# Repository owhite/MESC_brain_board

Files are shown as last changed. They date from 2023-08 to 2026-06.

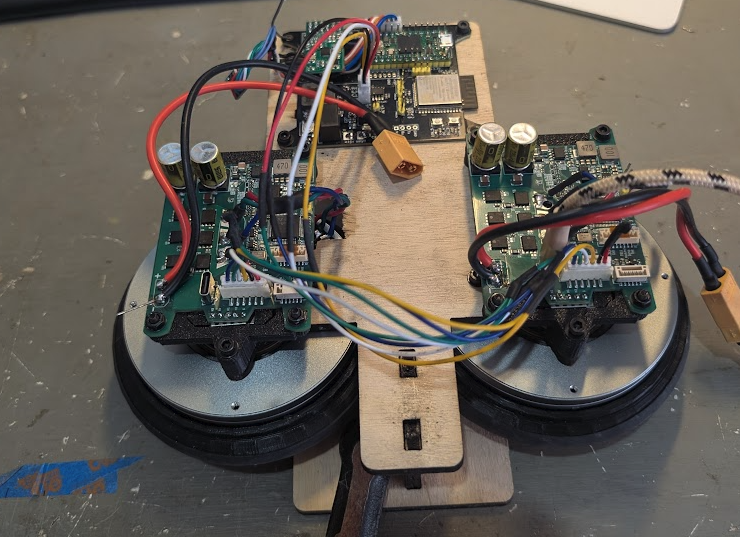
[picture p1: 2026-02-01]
DOCS/IMAGES/ROBOT_CARCASS1.png

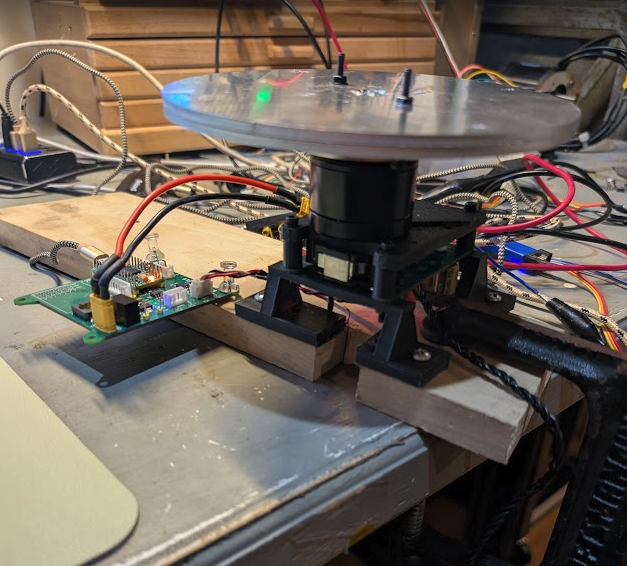
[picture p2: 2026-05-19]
modeling/PICS/rig2.png

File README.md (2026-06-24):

# Balancing Robot Design and Implementation

This repository is a structured set of lab notes and implementation records for developing a two-wheeled self-balancing robot. It documents the workflows from physical modeling and parameter measurement through firmware design, control implementation, and experimental validation.

The focus is on reproducibility and engineering rigor: measured motor parameters, deterministic control-loop behavior, system identification, control design tradeoffs, and verification testing are all captured alongside working code and experiments.

Topics covered include:
- Control design and validation workflows for balancing robots
- Motor parameter measurement (phase resistance, d/q inductance, damping)
- Deterministic embedded firmware structure for real-time control
- Encoder integration and signal integrity checks
- CAN communication and timing behavior
- Failure modes and debugging notes
- Practical test methods and instrumentation results

These notes are intended to make the development and validation process transparent and repeatable, not just to present final code.

## My balancing robot journey, specs and testing

* A subset of steps required to get a robot to stand [[LINK](DOCS/balancing_checklist.md)]
* Common issues that can break balancing in the brain board project [[LINK](DOCS/balancing_failures.md)]
* Firmware design choices that keep the balancing control loop deterministic [[LINK](DOCS/determinism_design.md)]
* Measuring phase resistance, d-axis, and q-axis inductance of a BLDC Motor [[LINK](DOCS/BLDC_inductance_measurement.md)]
* Dial in ChatGPT to be skeptical lab partner: [[LINK](DOCS/chatGPT_tips.md)]
* Development of the robot control board [[LINK](brainboardV1.2/README.md)]
* OTA programming [[LINK](RPI_OTA_BRIDGE/README.md)]
* Finalizing the modeling workflow [[LINK](modeling/README.md)]

## Not totally coherent discussions:
* [LQR](DOCS/learn_LQR.md). 
* Using the MT6701 [[LINK](DOCS/MT6701.md)] → works great but required some minor modifications to MESC position and [velocity measurement](DOCS/pos_vel_CAN.md)
* Measuring jitter on the MESC [[LINK](DOCS/jitter_testing.md)] → none found at current operating speeds
* Implementing CAN [[LINK](DOCS/CAN.md)]
* Notes about MESC [[LINK](DOCS/MESC_control_variables.md)]
* The inadequacies of PID [[LINK](DOCS/PID_position.md)]. 
* General description of firmware: [LINK](DOCS/teensy_firmware_walkthrough.md). 
* Brain board firmware [[LINK](DOCS/software_specs.md)]

## Laboratory notes, 2025

* [Position hold](DOCS/sept12_position_hold.md)
* [Controller issues](DOCS/sept18_controller_issues.md)
* [Torque nonlinearity](DOCS/sept19_torque_nonlinearity.md)
* [PID notes](DOCS/sept23_PID_notes.md)
* [Least squares](DOCS/sept30_least_squares.md)
* [Torque response](DOCS/oct03_torque_response.md)
* [LQR modeling](DOCS/oct11_LQR_modeling.md)
* [LQR height](DOCS/oct12_LQR_height.md)
* [IMU testing](DOCS/nov16_IMU.md)

## Let's be real

**You probably will not want to hear this.** If you came here for the code to make a balancing robot, it is here, but it probably wont help. 

You might assume building a balancing robot is mostly a matter of assembling parts and flashing someone else’s code onto it. I used to think that too — until I finally worked out how to create on one. Balancing robots are not just bolted together -- they are tuned and integrated. Everything about them depends on tight interactions between hardware, sensors, motors, and feedback loops, and those interactions are different for every single robot.

A balancing robot is a dynamic control system, not a static device. It’s constantly trying to predict its own motion, measure its own tilt, compensate for delays, cancel vibration, and stabilize itself against gravity — hundreds of times per second. That means even small differences in hardware completely change the way the controller behaves. For example:

- Motors & ESCs: Different torque curves, different dead zones, different current limits, different FOC tuning.
- Wheels & tires: Diameter, traction, inertia, compliance — all change how the robot responds to torque.
- IMU: Sensitivity, noise, mounting vibration, sample timing, bias drift — all affect measured tilt.
- Microcontroller timing: Loop rate, jitter, scheduling delays, filter performance — all shift the controller behavior.
- Physical build: Height of the center of mass, frame stiffness, mass distribution — all change the robot’s dynamics.

If you change any of these, even slightly, the controller behaves differently. That’s why tuning is so time-consuming: you’re adjusting a control law to match the physics and imperfections of your specific robot.

_You are welcome to take my code and run it on your bot._ But unfortunately just like musical instruments or high-performance cars, balancing robots need to be customized, adjusted, and dialed in until the system “feels right.” The code is just the beginning; the tuning is the craft.

Why? Well:
- Your robot will not balance without a lot of tuning.
- What's most important to use this project as a prompt for making your own system
- Tuning is the real work — not a flaw, but part of the fun
- What really makes a robot stand is eliminating all the problems like jitter, timing issues, CAN communications, and modeling

**Finally, dearest reader**... I care about you, youre adorable, but quite unfortunately one the PCB for one of the ESCs that I use is closed source. Nothing would delight me more to make it open and I will try. For a while, I was using the Flipsky Mini FSESC6.7 pro 70A but I got tired of blowing them up because of cheap parts. Some day I will make a balancing bot that runs on [moteus](https://mjbots.com/products/moteus-r4-11) or [odrive](https://odriverobotics.com) but right now that is not a priority. 

For these reasons and others you cant expect to use this repo to build a balancing robot like some sort of kit.

## The really great news is there is a new source of help. 

I want to be transparent about this: building a robot is not about writing code. I've written code for 20 plus years, in my case I worked through the entire project with ChatGPT as a kind of engineering partner. ChatG helps with asking questions, testing ideas, refining approaches, debugging weird behavior, and iterating the design over and over.

A balancing robot is a complex closed-loop control problem. As far as I know I never would have been able to use Google to address how robots behaves. ChatGPT creates the ability to explore those problems conversationally:

- When I wasn’t sure whether the IMU filtering was right, I asked it to analyze my data.
- It is incredible at helping with plotting results
- When I had motor vibration I couldn’t explain, I used chat to brainstorm possible causes and experiments.
- It taught me everything about LQR, interpretted equations, supplied python code to perform most of the calculations. It involved a lot of debugging -- when the LQR gains seemed wrong, I walked through the math with it.
- When the ESC behavior looked inconsistent, we debugged line by line until we understood it.
- When I needed to test an assumption, it helped me design the test.
- When something behaved strangely, I could describe it and get three possible hypotheses to try.
- ChatG is uncanny at image analysis. It reads part numbers off of chips and will take you to the spec sheet. Take a picture of a square wave of your scope - - the damn thing will tell you the frequency, amplitude of the wave. It also taught me how to set up [one-shot measurements](DOCS/BLDC_inductance_measurement.md). 

The project was far less like copying code from the internet and more like having a very patient senior engineer building one-off code bundles to eventually get this thing to stand. 

**We live in a world of prompt-driven engineering:** I shaped my thinking through prompts, refined those prompts based on the robot’s behavior, and used those conversations to build understanding that would have taken months on my own. ChatGPT didn’t “solve the problem” — it helped me reason through it, step by step.

So if you see this robot standing and balancing in a video, know that behind the scenes was not just hardware and code — it was hundreds of micro-conversations, experiments, adjustments, and iterations. ChatGPT was the scaffolding that helped me structure that process.

## ACKNOWLEDGEMENTS
This project would be completely impossible without the help, support and guidance of David Molony, developer of [MESC firmware](https://github.com/davidmolony/MESC_Firmware.git). Use of the MESC firmware is described throughout this repo.

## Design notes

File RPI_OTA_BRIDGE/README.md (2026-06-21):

# Headless Teensy OTA Bridge (Pi Zero 2 W)

Reference commit: `89e9f187`
Date: 2026-05-05
This codebase was created from the prompt in [PROMPT.md](PROMPT.md).

## To invoke upload

Documentation update reference commit: `c7eb63e1`

Working method (validated): run from your PlatformIO project that contains `bridge_upload.py` and its `platformio.ini` wiring (example project: `teensy40/blink`).

```bash
cd /path/to/teensy40/blink
pio run -t bridge_send
```

The same command with explicit overrides:

```bash
TEENSY_BRIDGE_HOST=teensybridge.local TEENSY_BRIDGE_USER=owhite TEENSY_BRIDGE_DROP_DIR=/home/owhite/teensy_drops pio run -t bridge_send
```

Help command for this integration:

```bash
pio run -t bridge_help
```

Optional wrapper commands (if `pio_bridge.sh` is present in that PlatformIO project root):

```bash
./pio_bridge.sh --bridge_help
./pio_bridge.sh --bridge_send
```

What does not work from this repository root (`RPI_OTA_BRIDGE`) unless you add those custom targets to that project:

```bash
pio run -t bridge_send
pio run -t bridge_help
```

**NOTE:** some times you have to press the button on the teensy, but usually just for the first upload of the session. 

## Upload/Download Expansion Plan

For the new Teensy -> Pi -> Desktop run-log return pipeline, use:

- [RPI_UPLOAD_DOWNLOAD_CHECKLIST.md](RPI_UPLOAD_DOWNLOAD_CHECKLIST.md)

Phase 1 implementation reference commit: `c7eb63e1`

## Construction notes

This workspace implements your spec for a headless Raspberry Pi OTA bridge:

- Desktop -> Pi transport via `scp`
- Pi-side file completion trigger via Linux inotify (Python Watchdog `on_closed`)
- Flash target via `teensy_loader_cli --mcu=TEENSY40 -w -s -v`
- Upload status persisted to `/home/<your_pi_username>/teensy_drops/last_upload_status.log`
- Processed artifacts (`.hex`) moved to `/home/<your_pi_username>/teensy_drops/processed`

## Project Layout

- `pi/udev/49-teensy.rules`: non-root Teensy bootloader access
- `pi/scripts/install_teensy_loader_cli.sh`: build/install PJRC loader on ARM
- `pi/scripts/install_udev_rules.sh`: deploy udev rule to `/etc/udev/rules.d/`
- `pi/bridge/bridge.py`: watchdog service implementation
- `pi/bridge/requirements.txt`: optional Python dependency list (`watchdog`)
- `pi/systemd/teensy-bridge.service`: persistent service unit
- `pi/scripts/install_bridge_service.sh`: install Python dependency and systemd service
- `pi/listener/serial_listener.py`: Pi-side Teensy USB serial capture worker
- `pi/systemd/teensy-listener.service`: persistent Teensy serial listener unit
- `pi/scripts/install_listener_service.sh`: install serial listener dependency and service
- `desktop/upload_to_pi.py`: PlatformIO post-upload script (SCP + SSH log follow)
- `desktop/platformio.ini.snippet`: required PlatformIO config snippet

## mounted Pi: 
pi mount

## Pi Provisioning Baseline

Raspberry Pi OS Lite (64-bit), hostname `teensybridge`, SSH enabled, Wi-Fi configured.

Note: Connect using mDNS name `teensybridge.local` from your desktop.

Required packages from spec are covered by scripts:

- `build-essential`
- `libusb-dev`
- `python3-watchdog`
- `git`

Note: On Raspberry Pi OS trixie (PEP 668), the bridge installer uses `python3-watchdog` from apt instead of pip.

## Pi Installation Steps

Run these on the Pi from this repository root:

```bash
chmod +x pi/scripts/*.sh
./pi/scripts/install_teensy_loader_cli.sh
./pi/scripts/install_udev_rules.sh
./pi/scripts/install_bridge_service.sh
./pi/scripts/install_listener_service.sh
```

If your Pi login user is not `pi`, set `BRIDGE_USER` before the bridge install step:

```bash
export BRIDGE_USER=<your_pi_username>
./pi/scripts/install_bridge_service.sh
./pi/scripts/install_listener_service.sh
```

The installer renders the systemd unit with your user home and sets `TEENSY_DROP_DIR` automatically.

Then verify:

```bash
systemctl status teensy-bridge.service --no-pager
systemctl status teensy-listener.service --no-pager
journalctl -u teensy-bridge.service -n 50 --no-pager
journalctl -u teensy-listener.service -n 50 --no-pager
```

Quick listener smoke test (on Pi):

```bash
RUN_ID=$(date +%Y%m%d_%H%M%S)_smoke
echo "$RUN_ID" > /home/$USER/teensy_runs/current_run_id
sleep 2
cat /home/$USER/teensy_runs/$RUN_ID/status.json
```

Completion marker note:

- The listener marks a run `completed` on either:
	- JSON line with `"msg":"RUN_DONE"` (optional matching `run_id`), or
	- plain-text line containing `RUN_DONE` (optionally `RUN_ID=<run_id>`).

Listener growth safety defaults:

- Per-run timeout: `RUN_TIMEOUT_SEC=120`
- Per-run byte cap: `MAX_RUN_BYTES=20971520` (20 MiB)
- Per-run record cap: `MAX_RUN_RECORDS=200000`
- Old run retention cap: `KEEP_RUN_DIRS=200` (oldest run directories are pruned)

Additional safety behavior:

- Run logs are overwritten per run ID (not appended) to prevent restart replay growth.
- Completed/timed-out/error runs are not replayed on service restart.

## Desktop PlatformIO Integration

Validated current workflow (recommended):

1. Use your PlatformIO project with bridge targets already wired (example: `teensy40/blink`).
2. From that project directory run:

```bash
pio run -t bridge_send
```

3. Optional environment overrides:

```bash
export TEENSY_BRIDGE_HOST=teensybridge.local
export TEENSY_BRIDGE_USER=<your_pi_username>
export TEENSY_BRIDGE_DROP_DIR=/home/<your_pi_username>/teensy_drops
```

If your Pi hostname differs, set `TEENSY_BRIDGE_HOST` accordingly.

Alternative workflow (this repo's generic hook):

1. Copy `desktop/upload_to_pi.py` into your PlatformIO project root.
2. Add contents of `desktop/platformio.ini.snippet` to your `platformio.ini`.
3. Run `pio run -t upload` from that PlatformIO project.

## One-Command Run Cycle (Desktop)

Desktop orchestration reference commit: `c7eb63e1`

Use this script to run one full cycle:

1. write a new `run_id` on Pi (`current_run_id`)
2. build + upload firmware (`pio run -t bridge_send`)
3. wait for Pi listener terminal status (`completed`, `timed_out`, `error`, `size_limit`)
4. fetch `/home/<pi_user>/teensy_runs/<run_id>/` artifacts to local logs

From this repository root:

```bash
./desktop/run_cycle.py --firmware-dir /path/to/teensy40/blink --user owhite --host teensybridge.local
```

Optional arguments:

```bash
./desktop/run_cycle.py \
	--firmware-dir /path/to/teensy40/blink \
	--logs-dir ./logs \
	--wait-timeout 240 \
	--keep-local-runs 100 \
	--user owhite \
	--host teensybridge.local
```

Local retention behavior:

- `--keep-local-runs` (default `100`) prunes oldest local run directories in `--logs-dir` after each run.

Exit behavior:

- `0`: run completed and artifacts fetched
- `124`: listener timed out or wait timeout exceeded
- nonzero: build/upload/fetch/listener error

## Full End-to-End Cycle (Runbook)

Documentation cycle reference commit: `c7eb63e1`

Use this sequence for the complete workflow:

1. Confirm Pi services are active:

```bash
ssh owhite@teensybridge.local "systemctl is-active teensy-bridge.service teensy-listener.service"
```

2. Run one full desktop cycle (build -> flash -> wait -> fetch):

```bash
cd /Users/owhite/balancing-robot-notes/RPI_OTA_BRIDGE
./desktop/run_cycle.py --firmware-dir /Users/owhite/balancing-robot-notes/teensy40/RPI_upload_download --user owhite --host teensybridge.local
```

3. Find the newest fetched run directory:

```bash
LATEST_RUN="$(ls -1t logs | head -n 1)"
echo "$LATEST_RUN"
ls -la "logs/$LATEST_RUN"
```

4. Verify outcome and key metrics:

```bash
cat "logs/$LATEST_RUN/status.json"
```

Expected success shape:

- `state` is `completed`
- `error` is empty
- `records` and `bytes` are nonzero

5. Inspect captured logs:

```bash
head -n 20 "logs/$LATEST_RUN/serial_raw.log"
head -n 20 "logs/$LATEST_RUN/serial_parsed.jsonl"
```

Expected log semantics:

- first meaningful marker is `RUN_START`
- periodic data lines follow
- completion marker `RUN_DONE` is present

If run ends as `timed_out` but artifacts exist, transport/capture worked and completion marker was not observed before timeout.

## Runtime Behavior

On upload:

1. Desktop script clears the remote status log and ensures drop directories exist.
2. Desktop script copies firmware (`.hex`) via `scp`.
3. Pi watchdog sees a file close event (`on_closed`) for `.hex` and runs teensy loader.
4. Desktop script streams `tail -f /home/<your_pi_username>/teensy_drops/last_upload_status.log`.
5. Desktop script exits success only when `EXIT_CODE=0`; otherwise exits with error.

## Notes

- The bridge is intentionally headless and unattended.
- Processed firmware is renamed with timestamp and result suffix (`.ok.hex` or `.fail.hex`).
- Soft reboot mode (`-s`) avoids button presses when the running firmware exposes a USB path that supports reboot requests.
- If firmware is crashed or USB is unavailable, manual button press may still be required.
- Trigger semantics: upload starts on inotify `on_closed` for new `.hex` writes in the drop folder.

## Known Failure Modes

1. **No USB events on Pi (`dmesg -w` stays silent)**
	- Symptom: plugging/unplugging Teensy shows nothing in `sudo dmesg -w`.
	- Cause: wrong Pi Zero 2 W port (`PWR IN` instead of `USB` data), bad OTG adapter, or charge-only cable.
	- Fix: use the `USB` data port with a known data cable/OTG adapter; verify events appear in `dmesg -w`.

2. **SSH key login fails (`Permission denied (publickey)`)**
	- Symptom: `ssh <user>@teensybridge.local` reaches host, then auth fails.
	- Cause: wrong SSH username or mismatched key in Imager/authorized_keys.
	- Fix: connect with the correct username; verify matching key pair; use password auth for first boot if needed.

3. **`externally-managed-environment` during install**
	- Symptom: pip install fails on Raspberry Pi OS trixie.
	- Cause: PEP 668 system Python protections.
	- Fix: installer uses apt package `python3-watchdog`; avoid system pip installs for bridge dependency.

4. **Loader waits forever (`Waiting for Teensy device...`)**
	- Symptom: `teensy_loader_cli` parses firmware then waits for device.
	- Cause: Teensy bootloader not entered yet, USB path unavailable, or firmware cannot soft-reboot.
	- Fix: try `-s` soft reboot path first; if still waiting, press Teensy button; confirm USB visibility with `lsusb`/`dmesg`.

5. **HEX/BIN mismatch parse errors**
	- Symptom: errors like `error reading intel hex file ...firmware.bin`.
	- Cause: dropping `.bin` while loader expects Intel HEX.
	- Fix: bridge is `.hex`-only; ensure desktop uploader transfers `.hex` artifacts.

6. **Upload not triggered even with file in drop folder**
	- Symptom: old file present but no flash attempt.
	- Cause: trigger is event-based (`on_closed`), not presence-based.
	- Fix: copy/write a new `.hex` file into the drop directory; stale files do not retrigger.

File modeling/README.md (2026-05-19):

# Pendulum State-space Model Generation and Validation

## GOAL: Develop a final workflow for determining the gains to run a two wheel robot (TWR)

The intention here is to create a reproducible workflow for generating and validating the balancing robot model and LQR controller gains. Physical parameters are derived from CAD STL geometry and measured part masses, then automatically converted to SI units and used to compute CoM, inertia, and the linearized state-space model.

Model correctness is verified through automated checks including controllability/observability rank, continuous and discrete closed-loop pole analysis, time-constant estimation, and time-domain closed-loop simulation with actuator effort plots. This validation pipeline ensures the controller gains are consistent with the modeled physics before deployment to hardware.

## Steps to model validation
- Design your model in CAD 
- Export each stl part individually
- Carefully weigh each part and record
- Generate data/GL80/GL80_parts.json
  - describe values that are used in this json [like this](data/GL80/GL80_params.json)
  - the global coordinate system for all STLs should be the same
  - the scripts assume the bot is sitting on the ground plane
  - units for STL parts are grams and millimeters
  - parts like the wheels get combined into a single STL and weight reflects both wheels
  - record other values (stl files, origin, axis of rotation)  

My current bot in CAD:

CAD pic of balance bot

## Robot design tips
(future plan: break this out into a separate document)

- For most cases with a balancer, the motor is mounted on the bot
  - A portion of the motor is serving as the wheels (rotor)
  - Another portion is stationary (stator)
  - For the CoM calculations you'll need to figure out the masses of those parts
- Mount the imu over the axle
- The IMU should be placed away from the axis of rotation
- Vibration isolation is a huge issue [see here](../teensy40/vibration_testing/README.md) and [here](..//teensy40/mpu6050_spec.md)
- Construct a robot [carcass](../DOCS/IMAGES/ROBOT_CARCASS1.png). This allows you to test all cabling, connections and motor mounts before cramming it all into your TWR. It also greatly simplifies spinning the motor, parameterizing the ESC, using a scope, taking measurements and general debugging. This is another one of those: "if you cant get this step to work, youre not going to get the final robot to work". 

## General workflow

```plaintext
$ ./spin_decay.py /dev/cu.usbmodem181813701 --J 0.00309
   ↓
   └── compute damping coefficient (b_Nm_s_per_rad)
   ↓

$ ./apps/generate_TWR_data.py -i data/GL80/GL80_params.json 
   ↓
   ├── computes mass, CoM, inertia
   └── writes JSON GL80_metadata.json
   ↓
$ ./verify_TWR_data.py TWR_bot_data.json
   ↓
   └── sanity checks lots of values
   ↓
View results: 
   ↓
   └── ./plot_TWR_response.py TWR_bot_data.json 
```

**NOTE:** I strongly recommend that you review each of the steps with ChatGPT. Show it the code and describe what you are doing, chat can play a role of lab partner and explain the purpose of each step. 

These are useful prompts for ChatG as you work through your data:
- What is your interpretation of these eigen values?
- Tell me about how total damping was calculated
- How did you arrive at the conclusion that the model and LQR data consistent and stable?
- Lets reality check my COM CoM 
- Lets reality check Moment of inertia
- How do all of my results compare to other 1.5kg sized balancing bots?
- What do you mean by "Q/R tradeoff"? 

## Motor / flywheel inertia calculation 

One part of modeling is calculating the damping coefficient of the motor `b_Nm_s_per_rad`, the rotational viscous damping coefficient. It models torque loss proportional to angular velocity: `𝜏_loss = 𝑏𝜔`

It is needed to:
- Correctly capture energy dissipation in the motor + drivetrain
- Place realistic damping terms in the state-space model
- Prevent overly aggressive or unstable LQR gains
- Get the simulation and real hardware to match.

Set up value:
- Load ../teensy40/can_posvel_on to the teensy
- This is the rig I used: [LINK](PICS/rig1.png)
- Spun with a cordless drill
- Flywheel treated as a solid flat disk
- Phase wires on motor were not connected to ESC
- Measured mass: 𝑀 = 429g = 0.429 kg
- Measured diameter: 240 mm → radius
- 𝑅 = 0.12 m
- For a solid disk about its central axis:
  - 𝐽 = 1/2 ⋅ M ⋅ R²

Substitute in mass:
- 𝐽 = 1/2 ⋅ 0.429 (0.12)² ≈ 0.00309 kg ⋅ m²
- This J was used to convert the measured spin-down time constant b=J/τ
- Run this command: `$ ./apps/spin_decay.py /dev/cu.usbmodem181813701 --J 0.00309`
- For capture diagnostics, append: `--raw-capture --raw-jsonl spin_decay_raw.jsonl --sample-csv spin_decay_samples.csv`
  - `--raw-capture`: plots raw sample points and prints sample-spacing/velocity-step diagnostics (helps spot jitter or dropouts).
  - `--raw-jsonl spin_decay_raw.jsonl`: writes every parsed JSON line with host receive time and an accept/ignore reason (helps debug sender filtering and malformed lines).
  - `--sample-csv spin_decay_samples.csv`: writes the accepted sender samples used for fitting (`capture_index`, `host_t_s`, `t_us`, `t_s`, `sender`, `pos`, `vel`) so you can post-analyze the fit window.

**Result:**   
Plot result

From the plot text:
- τ = 2.246 s (since 𝑏/𝐽 = 0.4463)
- R² = 0.932 → solid fit for real hardware
- J = 0.00309 kg·m² (flywheel)

Therefore:  

𝑏 =  𝐽 / 𝜏_time = 0.00309/ 2.246 = =0.00138 N⋅m⋅s/rad

The identified viscous damping coefficient represents the linearized low-speed loss of the motor–flywheel system under open-circuit conditions. Quadratic (aerodynamic) losses are present but intentionally excluded for LQR linear modeling.

ChatG says this is exactly the right order of magnitude for:
- A 300 g BLDC
- Decent bearings
- Moderate windage
- Open-circuit (not connected to ESC)

## GB36-2 motor -- another spin down experiment
Previous work was for a cubemars GL60. 

Now testing a new motor: 

` ./apps/spin_decay.py /dev/cu.usbmodem181813701 --J 0.000881 --raw-capture --raw-jsonl spin_decay_raw.jsonl --sample-csv spin_decay_samples.csv`

- This is the rig I used: [LINK](PICS/rig2.png)
- Primary platter: aluminum disk, D = 150 mm, thickness = 6.4 mm
- Secondary platter: D = 58 mm, mass = 52 g
- Assumed aluminum density for primary platter: ρ = 2700 kg/m³
- Estimated inertia:
- J1 (150 mm plate) ≈ 8.59e-4 kg·m²
- J2 (58 mm, 52 g plate) ≈ 2.19e-5 kg·m²
- J_total ≈ 8.81e-4 kg·m²

RESULT: `b_Nm_s_per_rad = 0.00017`

## Review of TWR data

Run: ```./apps/generate_TWR_data.py -i data/GL80/GL80_params.json ```

The program reads the STL assembly and per-part masses to compute the robot’s total mass, body and total centers of mass, and body moment of inertia, then builds the linearized continuous and discrete state-space models of the balancing robot about the wheel axle. It then computes the continuous and discrete LQR gains and reports the closed-loop eigenvalues to verify stability and dynamic behavior.

The program computes the closed-loop eigenvalues of the system using the LQR gains for both the continuous and discretized state-space models. These eigenvalues indicate whether the controller stabilizes the robot and show how fast each dynamic mode decays or oscillates. Continuous eigenvalues must have negative real parts and discrete eigenvalues must lie inside the unit circle for the balance controller to be stable.

```plaintext  
    "params": {
	"b_Nm_s_per_rad": 0.001379,
	"friction_term": 0.05,
	"wheel_radius": 52.78,
	"axle_origin": [0.0, 0.0, 52.78],
	"axle_vector": [0.0, 1.0, 0.0],
	"input_path": "/Users/owhite/MESC_brain_board/modeling/data/GL80",
	"output_file_name": "GL80_TWR_params.json"
    }
```

Review all these values
| Parameter | Units | Interpretation |
| --- | --- | --- |
| com_total_mm  | mm | consistent with 13 cm above ground |
| com_body_mm | mm | ideal for stable LQR tuning |
| m_total | kg | consistent with geometry and inertia |

**1. Continuous-time eigenvalues**
```
  "eig_cont": [
    [
      -52.967859199698964,
      0.0
    ],
    [
      -7.067002375469126,
      0.0
    ],
    [
      -0.45941090750909785,
      0.44746221761027616
    ],
    [
      -0.45941090750909785,
      -0.44746221761027616
    ]
  ],
```

**Interpretation**

Verifying the system poles (eigenvalues) confirms that the modeled dynamics and computed controller gains **actually produce a stable closed-loop system with the expected response speeds and damping**. It provides a direct, quantitative check that the LQR design, numerical implementation, and exported model data are internally consistent before deploying the controller to hardware.

ChatG is REALLY good at interpretting the eigen values. I have developed gains for two bots and they were different in behavior, but it has useful things to say about both sets. In this current case:

- The eigenvalues include a complex conjugate pair (nonzero imaginary parts), which means the closed-loop system is stable but underdamped — it will exhibit decaying oscillatory modes rather than purely monotonic decay. Stability requires negative real parts (continuous) or magnitudes < 1 (discrete), not that all eigenvalues be purely real.
- For a balancing robot with LQR, having a complex conjugate pole pair just means one mode is underdamped — you’ll get a small, decaying oscillatory component in the response rather than purely exponential (non-oscillatory) decay. 
- What is important is:
  - continuous poles have negative real part, and
  - discrete poles have magnitude < 1, and these do. 

|Mode | Eigenvalue Time constant τ = –1/λ  | Interpretation
| --- | --- | --- |
|1–2 ≈ –1.14  | ≈ 0.88 s |Fast stabilization modes (angle and angular rate regulation).
|3–4 ≈ –0.053 | ≈  19 s	 | Very slow modes (wheel position drift, integral-like effect).

So, physically:

- The LQR is actively damping the body angle and angular velocity quickly (under 1 second response time).
- The cart position / wheel drift is only weakly stabilized — it will slowly creep but remain bounded.
- That’s exactly what you expect for a torque-controlled balancing robot with standard LQR weights: prioritize angle balance, tolerate slow translation.

**2. Discrete-time eigenvalues**
```
  "eig_disc": [
    [
      0.8995269476247606,
      0.0
    ],
    [
      0.9859653460432849,
      0.0
    ],
    [
      0.9990812001385199,
      0.0008941024634992121
    ],
    [
      0.9990812001385199,
      -0.0008941024634992121
    ]
  ],
```

**Interpretation**

- These correspond to a discrete-time system at 500 Hz (Ts = 0.002 s).
- All values are less than 1, so the system is discretely stable.
- 0.8995 → fast decay, about 19 ms time constant (very quickly dies out).
- 0.9860 → slower decay, about 0.14 s time constant.
- The last two form a complex conjugate pair, so that mode is oscillatory but decaying 

|eig | λ_cont (approx) | τ = –1/λ
| --- | --- | ---
| 0.89953 | –52.97 s⁻¹ | 0.0189 s |
| 0.98597 | –7.07 s⁻¹ | 0.142 s |
| 0.99908 ± j… | –0.459 s⁻¹ | 2.18 s |

----

Run: ```$ ./apps/verify_TWR_data.py data/GL80/GL80_metadata.json ```

Results:

Verification result

Make a screen shot of your output, show it to brother G, and ask for an interpretation of the data it sees

----

Run: ```$ ./apps/plot_TWR_response.py data/GL80/GL80_metadata.json ```

Check system dynamics and actuator demand by giving it some negative torque at then plot a smooth exponential decay toward zero as the robot rebalances.

Plot result

Comments:

- Units (e.g., mm → m, g → kg) and inertia scaling are probably correct.
   - If they were off the smooth decay either be a sluggish drift or a chaotic oscillation.
- 𝑄 and  𝑅 weights are balanced to keep torque effort reasonable, and not over-penalize wheel displacement.
- Mechanical and electrical damping are promising

The bottom plot shows
- Large initial corrective torque
- Rapid decay toward ~0
- No chatter
- No sustained bias
- No oscillatory control effort

That implies:
- No hidden unstable mode
- No sign error in B or K
- No unit blow-up in inertia or lever arm
- Reasonable Q/R tradeoff

If something were wrong, this plot would usually show:
- Repeated torque sign flips
- Growing amplitude
- Saturation-scale commands
- Slow nonzero bias

The simulated closed-loop step response shows bounded control effort and monotonic state decay consistent with the computed closed-loop poles and time constants.

This is validation that the gains **_for the model of the robot_** are probably okay. It's all great but _on balance_ (pun intended) this does **NOT** mean the gains when applied physical robot is going to behave as well, but you cant expect your model to work without these values behaving properly. 

## This is currently my prompt to create a generic motor damping workflow:

You are acting as a **skeptical engineering collaborator**. Your role is to challenge assumptions, verify methodology, and ensure physically valid results.

I am measuring the **rotational damping coefficient (b)** of a motor (units: N·m·s/rad) using a **spin-down experiment**.

## Context

* The motor is part of a robotics/control system (e.g., balancing robot, actuator, etc.)
* I want to use this parameter in a **physics-based model** (state-space / LQR / simulation)
* The goal is to obtain a **physically meaningful and reproducible value of b**

## Your Responsibilities

1. **Do not assume correctness** of my setup or method
2. Identify **what exactly is being measured** (mechanical vs electrical damping)
3. Ensure the result is **relevant to the real operating system**
4. Push for **quantitative validation**, not just plausibility
5. Flag **sources of error, bias, or hidden assumptions**

---

## Step 1 — Experimental Setup Review

I will describe my setup. You should:

* Ask clarifying questions if anything is ambiguous
* Identify what damping mechanisms are included:

  * viscous (b·ω)
  * Coulomb friction
  * aerodynamic drag
  * electrical damping (back-EMF / ESC behavior)
* Tell me whether this setup matches the damping seen in the real system

---

## Step 2 — Measurement Strategy

Help me design or refine a procedure to measure ω(t):

* Sensor choice (encoder, observer, etc.)
* Sampling rate requirements
* Data quality concerns (noise, quantization, filtering)
* Required velocity range for valid fitting

Be explicit about what would make the data unusable.

---

## Step 3 — Model Selection

We are assuming a model of the form:

τ_loss = b·ω

Critically evaluate:

* When this linear viscous model is valid
* When it breaks down (low speed, high speed, etc.)
* Whether a more complex model (e.g., Coulomb + viscous) is needed

---

## Step 4 — Parameter Identification

Guide me through extracting b from ω(t):

* Show the correct transformation (e.g., log-linearization)
* Define how to select a valid fitting region
* Explain how to detect non-exponential behavior
* Provide criteria for a “good” fit (R², residuals, consistency)

---

## Step 5 — Validation

Do not accept the result blindly. Require:

* Sanity checks on magnitude (order of magnitude reasoning)
* Sensitivity to measurement errors (J, noise, fit window)
* Cross-checks (e.g., different speed ranges, repeated trials)

---

## Step 6 — System Relevance

Help determine:

* Whether this measured b should be used directly in my system model
* Whether I need multiple values (e.g., mechanical vs electrical damping)
* How incorrect b would affect controller behavior (e.g., LQR)

---

## Step 7 — Final Output

Help me produce:

* A clearly stated value of b with units
* Assumptions under which it is valid
* Known limitations of the measurement
* Recommendations for improving accuracy

---

## Interaction Style

* Be concise but technically rigorous
* Challenge me if something seems wrong or incomplete
* Prefer quantitative reasoning over qualitative statements
* If uncertainty exists, estimate it

---

-----

Prompt complete, let's walk through an experiment:

The specs of my motor are the following:
- GB36-2 Gimbal 
- KV30 
- Configuration: 12N14P 
- Weight 128g 
- Internal resistance: 16.4 ohms

chatgpt suggests a flywheel of the approximate weight:

J ≈ 3×10−4 to 8×10−4 kgm2

I am going to order 

Use 3.2 mm aluminum for three platters.

At 150 mm diameter, each platter is approximately, Mass: ~153 g

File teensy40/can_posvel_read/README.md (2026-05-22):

## Teensy CAN Test Programs

**Teensy sketches** that can be loaded to send commands over CAN to the MESC-based ESC. Each one uses a different control channel built into the firmware.  

---

### `src/main.cpp`: POSVEL reader

The active `src/main.cpp` sketch is a POSVEL receiver/diagnostic for the current two-bus Teensy 4.0 bench wiring.

Key behavior:

- Configures CAN1 with the TWR mapping: RX pin 23, TX pin 22.
- Configures CAN2 with the TWR mapping: RX pin 0, TX pin 1.
- Reads extended MESC CAN traffic from both controllers.
- Tracks `CAN_ID_POSVEL` (`0x2D0`) counts and latest position/velocity for nodes 11 and 12.
- Emits a compact 1 Hz JSON summary rather than printing every POSVEL frame.
- Can optionally send zero-torque `CAN_ID_IQREQ` (`0x001`) to ESC node 11 on both CAN buses for sync/legacy testing.

Why the zero-IQREQ keepalive existed:

Older ESC firmware synchronized POSVEL publication to incoming `CAN_ID_IQREQ` frames. Bench testing showed autonomous POSVEL could stop after about 25.56 seconds without periodic IQREQ traffic because the ESC POSVEL scheduler used `DWT_CYCCNT / 168` as a 32-bit microsecond timebase, and that raw cycle-derived timestamp wraps at about 25.56 seconds on the F405. Incoming IQREQ frames re-anchored the scheduler, so a zero-torque IQREQ keepalive preserved low-dropout synchronized POSVEL behavior.

The ESC firmware has now been repaired: POSVEL scheduling uses a wrap-safe monotonic microsecond timebase while retaining the IQREQ-triggered sync/nudge path. A 60s `tx off` CAN test validated autonomous 500 Hz POSVEL from both ESCs across the old DWT wrap point with no missed, duplicate, or out-of-order POSVEL frames.

The keepalive in this sketch is therefore disabled by default. If it is re-enabled for sync experiments or for older ESC firmware, the sketch sends it on both CAN buses because TWR bench wiring routes ESC nodes across CAN1/CAN2; sending on only one bus can silently miss the target ESC.

Firmware status:

The long-term ESC-side fix has been completed in `MESCinterface.c`: keep IQREQ-triggered sync/nudge behavior, but use a wrap-safe monotonic time source for autonomous POSVEL scheduling. Real POSVEL payloads have also been restored: slot0 is wrapped mechanical position in radians, and slot1 is velocity in rad/s.

Useful summary fields:

- `rx_can1`, `rx_can2`: which Teensy CAN controller is receiving frames.
- `pos11_count`, `pos12_count`: per-node decoded POSVEL frame counts.
- `last_mid`: most recent MESC message ID seen, useful for spotting when traffic changes from POSVEL to other telemetry such as `0x2B6` motor current.

---

### 1. `can_id_adc1_2_req.cpp`
- Use **`can_id_adc1_2_req.cpp`** for simple normalized throttle testing.  
- **CAN ID:** `CAN_ID_ADC1_2_REQ (0x010)`  
- **Payload:**  
  - Bytes 0–3 = `throttle_mapped` (float, normalized between **-1.0 and +1.0**)  
  - Bytes 4–7 = unused (`0.0f`)  
- **ESC Behavior:**  
  - Treated like a remote throttle input.  
  - Internally assigned to `motor_curr->input_vars.remote_ADC1_req`.  
  - Negative values = reverse torque, positive = forward torque.  
- **How to use:**  
  - Open Serial Monitor at 115200 baud.  
  - Type a float between `-1.0` and `+1.0`.  
  - Teensy sends that throttle value over CAN once.  
  - The ESC will respond if its **`remote_ADC_can_id`** matches the Teensy’s node ID (set via terminal: `set can_adc <id>`).  

---

### 2. `can_id_iqreq.cpp`
- Use **`can_id_iqreq.cpp`** for direct current/torque control.  
- **CAN ID:** `CAN_ID_IQREQ (0x001)`  
- **Payload:**  
  - Bytes 0–3 = `Iq_req` (float, in **amperes of q-axis current**)  
  - Bytes 4–7 = unused (`0.0f`)  
- **ESC Behavior:**  
  - Written directly into `motor_curr->FOC.Idq_req.q`.  
  - This is raw torque control, bypassing throttle mapping.  
- **How to use:**  
  - Open Serial Monitor at 115200 baud.  
  - Type a float (e.g. `5.0` or `-3.0`).  
  - Teensy will continuously stream that torque request at 500 Hz.  
  - The ESC will respond if its **`remote_Iq_can_id`** matches the Teensy’s node ID (set via terminal: `set can_iq <id>`).  

---

### Debugging in STM32CubeIDE
If you want to trace the command as it flows through the ESC firmware, good debug breakpoints are:  

- **`CAN1_RX0_IRQHandler()`** → Confirms the packet arrived in the ISR and was queued.  
- **`TASK_CAN_packet_cb()`** → Confirms the packet was dispatched to the right handler (ADC1_2_REQ or IQREQ).  
- **`MESCinput_Collect()`** → Confirms the chosen input value (CAN vs UART vs ADC) is being forwarded into the motor control loop.

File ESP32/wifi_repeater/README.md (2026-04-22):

# ESP32 WiFi Repeater for Teensy Telemetry

This folder contains an ESP32 bridge that forwards Teensy telemetry from UART to TCP.

## Overview

Data path:

1. Teensy logs telemetry samples while in `SUP_MODE_BALANCE_TWR`.
2. Teensy does **not** transmit telemetry during active balance.
3. On transition `SUP_MODE_BALANCE_TWR -> SUP_MODE_IDLE`, Teensy starts a flush on `Serial4`.
4. ESP32 (`wifi_repeater`) reads UART2 and forwards bytes to a TCP client.
5. Desktop client (`connect_raw.py`) receives raw bytes over TCP.

## Important Distinction: USB Serial vs Telemetry UART

Teensy prints JSON status lines like these on **USB Serial** (`Serial`):

- `TELEM_LOG_START`
- `TELEM_FLUSH_START`
- `TELEM_FLUSH_END`

Those are **not** sent on `Serial4`.

Actual telemetry packets sent on `Serial4` are binary fixed-size packets (64 bytes each).

## Current Wire Settings

### Teensy side

- Telemetry UART: `Serial4` (pins 16/17)
- Baud: `921600`

### ESP32 side (`src/main.cpp`)

- WiFi SSID: `Love Factory`
- TCP port: `9000`
- UART: `UART2`
- RX pin: `16` (from Teensy TX / Serial4 TX)
- TX pin: `17` (to Teensy RX / Serial4 RX)
- UART baud: `921600`
- `LOSSLESS_MODE = true`

## Running the Desktop Receiver

From this directory:

```bash
cd /Users/owhite/balancing-robot-notes/ESP32/wifi_repeater
python3 connect_raw.py
```

Defaults used by the script:

- Host: `twr-repeater.local`
- Port: `9000`

If mDNS resolution fails, pass IP explicitly:

```bash
python3 connect_raw.py --host <ESP32_IP> --port 9000
```

## Raw Binary Output (Expected Behavior)

`connect_raw.py` prints raw TCP bytes to stdout. Telemetry packets are binary, so terminal output may look empty/garbled.

To verify data capture, save to file:

```bash
python3 connect_raw.py > telem_dump.bin
```

Then inspect:

```bash
wc -c telem_dump.bin
xxd -g1 -l 128 telem_dump.bin
```

## Workflow Check

1. Start ESP32 repeater.
2. Start desktop receiver (`connect_raw.py`) before ending balance session.
3. Run balance session on Teensy.
4. Exit to idle (button reset).
5. Confirm Teensy USB Serial prints:
   - `TELEM_FLUSH_START`
   - `TELEM_FLUSH_END` with remaining bytes `0`
6. Confirm `connect_raw.py` captured binary bytes (file size increases).

## Note

If no TCP client is connected during flush, ESP32 may consume UART bytes without forwarding them to a desktop receiver. Keep the TCP client connected before triggering the flush.

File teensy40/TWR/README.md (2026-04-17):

# TWR Testing

This folder currently contains two firmware trees:

- Active TWR firmware: `TWR/src`
- CAN-focused reference copy: `TWR/can_testing/src`

Important: recent CAN reliability work was developed and validated in the CAN-focused tree. Do not assume `TWR/src` and `TWR/can_testing/src` are identical.

## CAN Status (Latest)

Recent CAN-focused runs (dual ESC, dual bus) have been strong:

- 60 s runs at 500 Hz IQREQ (`tx_period_us=2000`) completed with:
  - zero TX failures,
  - zero RX overflow,
  - healthy CAN event dispatch timing,
  - near-zero to zero sequence misses (occasional single-frame blips).

This is good enough to proceed with robot integration testing.

## IMU Filter (Current `TWR/src`)

- Filter type: 6-DOF Mahony quaternion update.
- Gains:
  - `Kp = 0.5` (`twoKp = 1.0`)
  - `Ki = 0.1` (`twoKi = 0.2`)
- Accel correction gating:
  - full correction for low accel-magnitude error,
  - tapered correction until `|acc|-1` reaches `0.06 g`,
  - no accel correction beyond that.
  - Practical band is tighter than `0.85..1.15 g` (roughly around `0.94..1.06 g` with taper).
- `dt` guard:
  - measured from IMU timestamps,
  - clamped to nominal 1 ms when outside `0.5..5 ms`.
- Reported states:
  - `pitch_rad = asin(2*(q0*q2 - q3*q1))`
  - `pitch_rate_raw` from gyro Y,
  - low-pass filtered `pitch_rate` (`alpha = 0.15`).

## IMU Test Tool

Run:

```bash
python3 /Users/owhite/balancing-robot-notes/teensy40/TWR/IMU_test.py \
  -p /dev/cu.usbmodemXXXX \
  -b 921600 \
  --expect-n 200
```

Outputs and plot fields in `VERIFY_ANGLE` mode remain as documented by the script (`pitch`, `pitch_rate`, raw/filtered RMS, IMU age/valid, loop dt, optional verify motor torque).

## Open Control Note

The balance controller still needs continued tuning/validation for translational terms (`x`, `x_dot`, integral hold behavior) under real disturbance cases.

## Recent Code Changes (April 2026)

- Added a virtual-axle synchronization path in `balance_TWR_mode.cpp`:
  - computes yaw mismatch from wheel unwrapped distance/speed (`g_unwrap_l - g_unwrap_r`),
  - stores a tare-time yaw reference (`g_yaw_ref`),
  - computes relative yaw error and optional sync torque (`u_sync`) that is mixed into left/right torque commands.
- Added/kept the tare-time yaw reference capture so heading correction is relative to the start posture, not absolute wheel offsets.
- Added a button-release entry latch in `main.cpp` for balance start:
  - if entry angle is valid while pressed (green LED on), release still starts balance/tare even if angle shifts slightly at release.
- Updated IMU anti-drift handling in `main.cpp`:
  - Mahony integral remains enabled with moderated `Ki`,
  - integral clamp + ungated decay behavior,
  - bump holdoff window for accel correction during disturbances,
  - quiet-motion gating for accel correction while balancing.
- Balance command cadence defaults are aligned with the stable CAN profile used in testing (`tx_period_us = 2000`, 500 Hz) unless overridden by runtime command.

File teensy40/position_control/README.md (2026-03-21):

# Position Control Project Goals

## System Intent

Build a two-wheeled balancing robot with an actuated knee joint (Ascento-like concept), where the knee BLDC is driven through a planetary gearbox.

## Supervisory Control (Outer Loop)

- A custom brain board (Teensy 4.0) runs:
  - High-level control logic
  - State estimation
  - Knee position control
- Brain board communicates with MESC over CAN bus.
- Brain board sends torque commands.
- Brain board receives position/velocity feedback.

## Control Goal: Knee Position Control

Target behavior:

- Move to a commanded position.
- Hold position reliably.
- Be reproducible (same final angle each time).
- Work at low speeds.
- Be robust to gearbox friction/backlash.
- "Reliable and practical" performance is the objective, not precision servo-grade behavior.

## Position Control Strategy (Brain Board)

Use torque mode on MESC and implement position logic on Teensy:

`tau = Kp * (theta_ref - theta) - Kd * omega + tau_friction`

Where:

- `Kp`: position gain
- `Kd`: damping gain
- `theta_ref`: target position
- `theta`: measured position
- `omega`: measured velocity

## Friction Compensation (Required)

Planetary gearbox friction is significant and must be compensated.

- Static friction compensation (near-zero speed, nonzero error):
  - `tau_stiction * sign(error)`
- Coulomb friction compensation (during motion):
  - `tau_c * sign(omega)`
- Optional viscous term:
  - `b * omega`

## Backlash Handling

To improve repeatability:

- Always approach final target from one direction, or
- Intentionally overshoot and return to target from a consistent direction.

## Key Design Decisions

- Do not modify MESC to add position control.
- Use MESC as:
  - High-speed torque controller
  - Sensor reporting device
- Keep all position logic on Teensy.
- Run outer loop over CAN at approximately 200 to 500 Hz (start lower, then increase).

## Current CAN TX/RX Limitations (Must Be Treated As Requirements)

- Shared-bus dual-ESC robustness is not yet a required success mode for this phase.
- Accepted mode for project completion: single active ESC node (node 11).
- Prior testing indicates likely shared-bus interaction limits under higher load:
  - Arbitration/timing collisions between multiple telemetry publishers.
  - Phase alignment effects causing repeated collisions.
  - Added Teensy command traffic reducing telemetry fidelity at unlucky timing.
  - Physical-layer sensitivity (termination, wiring, stubs, transceiver behavior, unpowered-node behavior).
- Serial1 activity on Teensy has previously degraded CAN receive quality and should be minimized during control validation.
- "TX success" (`CAN_TXQ_SUM ok/fail`) confirms Teensy enqueue/write success, not guaranteed actuator torque application.
- Per-frame counter continuity is the preferred drop-confidence metric when available; loop-sampled "missed" estimates alone are insufficient.

## Practical Operating Constraints for V1

- Single ESC telemetry publisher at 500 Hz (node 11).
- Teensy command TX decimated below control loop rate (currently capped at ~500 Hz with 2 ms min TX spacing).
- Control loop may remain 1 kHz internally, but command updates should be rate-limited.
- If feedback age exceeds timeout threshold (currently 10 ms), command zero torque and enter safe state.

## Implementation Learnings (Added from Bench Testing)

- ESC telemetry contract for position mode:
  - POSVEL position payload must be radians (counter-test payload is not valid for control operation).
- Direction/sign calibration is a first-class requirement:
  - Torque sign and encoder sign must be verified on each rig before position sweeps.
- Large sweep behavior:
  - `timed_sweep` targets are interpreted relative to current position at command start.
  - `timed_sweep` command range is `-10000..10000` degrees.
  - Multi-turn commands are supported and require unwrap safety limits that scale with requested move size.
- Estimation robustness:
  - Controller damping should use velocity estimated from position deltas.
  - Implausible per-sample position jumps should be rejected before unwrap integration.
- Command shaping:
  - Torque clamp and slew-rate limiting are required to avoid runaway during fast error sign changes and backlash transitions.
- Stale feedback policy:
  - Brief CAN hiccups can trip strict stale thresholds; stale-fault policy should be tuned (timeout value and/or consecutive-stale logic).
- Validation workflow:
  - Prefer scripted sweep logs (`run_sweep.py`) and evaluate `TIMED_POS_DONE`, `final_err_rad`, `jump_total`, and `CAN_TXQ_SUM fail=0`.

## What We Care About

- Reproducible final position.
- Stable position hold.
- No sustained oscillation.
- No runaway while lowering.
- Minimal implementation complexity.

## Out of Scope (For Now)

- High-speed trajectory control.
- Industrial precision motion control.
- Perfect speed regulation.

## Implemented Control Constants (Current Code)

These values are defined in `src/timed_pos_control.cpp` and should be kept in sync with that file.

- Sweep/input:
  - `SWEEP_DEG_LIMIT = 10000`
  - Target is relative: `target = pos_start + sweep_deg * pi/180`
- Outer-loop gains/limits:
  - `POS_KP_DEFAULT = 0.32`
  - `POS_KD_DEFAULT = 0.012`
  - `POS_TORQUE_CLAMP_NM = 0.90`
  - `POS_TORQUE_SLEW_NM_PER_S = 45.0`
  - `POS_TORQUE_SIGN = -1.0` (rig-specific)
  - `POS_DONE_BAND_RAD = 3 deg`
- Friction/backlash helpers:
  - `STICT_TORQUE_NM = 0.32`
  - `COULOMB_TORQUE_NM = 0.10`
  - `STATIC_VEL_THRESH_RAD_S = 0.20`
  - `STATIC_ERR_THRESH_RAD = 0.03`
  - `BREAKAWAY_ERR_RAD = 0.20`
  - `BREAKAWAY_TAU_MIN_NM = 0.45`
- Estimation/shaping:
  - `VEL_FROM_POS_ALPHA = 0.25`
  - `CMD_TX_MIN_DT_US = 2000` (about 500 Hz max TX)
- Safety/fault thresholds:
  - `POSVEL_TIMEOUT_US = 10000`
  - `POS_RAW_ABS_MAX_RAD = 100`
  - `VEL_RAW_ABS_MAX_RAD_S = 500`
  - `UNWRAP_BASE_LIMIT_RAD = 40`
  - `UNWRAP_TARGET_MARGIN_RAD = 12`
  - `INVALID_FB_MAX_CONSEC = 3`
  - `POS_JUMP_BASE_RAD = 0.30`
  - `POS_JUMP_SPEED_RAD_S = 350`
  - `POS_JUMP_MAX_CONSEC = 8`

-----------------------------------------
## Thoughts about lower friction compensation:

This was set up for a gearbox. These are parameters to tweak for other setups:
- `STICT_TORQUE_NM` down substantially (often near zero)
- `COULOMB_TORQUE_NM` down substantially
- `BREAKAWAY_TAU_MIN_NM` down or disable
- `BREAKAWAY_ERR_RAD` likely smaller

## Re-tune control gains for lower reflected inertia/friction:
- `POS_KP_DEFAULT` usually lower than geared case (start conservative)
- `POS_KD_DEFAULT` usually higher relative damping to prevent ringing

## Tighten torque limits:
- `POS_TORQUE_CLAMP_NM` lower (direct drive can accelerate fast)
- `POS_TORQUE_SLEW_NM_PER_S` lower for safer command shaping

## Tighten completion criteria:
- `POS_DONE_BAND_RAD` smaller (better natural precision without backlash)

## Revisit unwrap/jump guards:
- `POS_JUMP_BASE_RAD` and POS_JUMP_SPEED_RAD_S likely lower (motion is cleaner/less stick-slip)

## Possibly tighten stale feedback behavior:
- `POSVEL_TIMEOUT_US` can often be stricter if motion is smoother and less disturbance-sensitive

## Re-evaluate sign and direction constants:
- `POS_TORQUE_SIGN` and any encoder inversion still must be validated on the new mechanical setup

----------------------
## Testing
- parameters are set for gearbox motor
- launch: `$ ./run_sweep.py -3600`
- sweep value does not include gear ratio
- creates `sweep_output.log`
- codex can open the output and review
- try: `timed_sweep 3600` to turn the motor
- try: `pwm_control` to use an RC transmitter for input
-------------------------

Demo video (https://www.youtube.com/shorts/7sQ_XWcPYlw)

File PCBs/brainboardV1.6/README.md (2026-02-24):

# MESC BRAIN BOARD 

A PCB and software development project for a balancing robot. 

The goal is to use a hobby Electronic Speed Controller (one open source [example](https://github.com/owhite/MP2-DFN), and this circuit for a [brain board](https://github.com/owhite/MESC_brain_board/blob/main/brainboardV1.0/MESC_brain_board.pdf), a teensy 4.0, and an ESP-32, in combination with [MESC firmware](https://github.com/davidmolony/MESC_Firmware).

## GENERAL APPROACH

A separation of concerns is divided across these architectures:

* **Teensy:** Runs the high-level brain → gait generator, balance estimator, RC inputs
* **MESC:** The firmware on the ESC for control → torque or velocity loops per joint
* **ESP32:** Easy to log and analyze later → pumps UDP to the computer
* **Desktop computer** → perfectly adequate way of viewing high speed data with UDP

## TEENSY 4.0
* 600+ MHz ARM Cortex-M7 — plenty of headroom for filtering, control loops, gait logic, telemetry
* Tons of I/O for IMU, encoders, RC input, WiFi (via ESP add-on), etc.
* Precise timing with elapsedMicros or interrupts for deterministic control
* Great for real-time control, sensor fusion, and behavior modeling

## MESC MOTOR CONTROLLER
* Deploys on simple DIY or commercially available ESC boards
* Executes low-level Field-Oriented Control (FOC) motor control 
* Built-in support for encoders, FOC, and torque estimation
* Accurate low-level motor control using current sensing
* Reads angular position from the MT6701 encoder via SPI or PWM
* UART/CAN interface (RX + TX)	Real-time communication with the Teensy
* PWM / FOC commutation w/ efficient, smooth motor operation

## OTHER BRAIN BOARD FEATURES
* RC receiver connector (for PWM/PPM/SBUS input)
* ESP32 UART serial programmer
* Power input connector
* Voltage divider (to monitor battery voltage)
* Push-button E-stop connector
* Power button (for system on/off)
* IMU connector (e.g., MPU-6050)
* Buzzer (for system alerts or E-stop signal)
* MESC I/O
* Reserved 2 GPIO pins on Teensy for emergency shutoff to MESC
* CAN connector (for MESC motor control)

## CAN BUS
* Full-duplex communication between Teensy and motor controllers
* Carries:
  * Commands: set_torque, set_velocity, enable_motor, zero_encoder, etc.
  * Telemetry: encoder position, estimated torque, velocity, fault codes
* Real-time performance with minimal latency
* Can support multiple motor controllers on the same bus

## MANY THANKS
This project would never happen without:
* [MESC firmware](https://github.com/davidmolony/MESC_Firmware). 
* [Netzpfuscher's](https://github.com/Netzpfuscher/TTerm) incredible TTerm and CAN work.
* [MP2](https://github.com/badgineer/MP2-ESC) an open source motor controller from badgineer. 

## NOTES
Ever wanted to change all the names of kicad files at once?

use this:
```
python3 replace_kicad_names.py VESC_brain_board MESC_brain_board
```

[[LINK](replace_kicad_names.py)]

## STILL NEEDS WORK
* Not great design w/ DC-DC conversion from high voltage VBat
* Replace out the IMU for a ICM-42688-P
* Order / revise pushbuttons for programming the ESP32
* Ensure 3.3V CAN transciever

## VERSIONS
* See github tag [pcb-v1](https://github.com/owhite/MESC_brain_board/releases/tag/pcb-v1) for V1.0
* Retreive with this command: "git checkout pcb-v1"

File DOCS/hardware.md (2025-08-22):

# Hardware considerations

## Project plan:

Gonna try to use my open source motor controller, the [MP2-DFN](https://github.com/owhite/MP2-DFN), and this circuit for a [brain board](https://github.com/owhite/MESC_brain_board/blob/main/brainboardV1.0/MESC_brain_board.pdf), a teensy 4.0, and an ESP-32, in combination with [MESC firmware](https://github.com/davidmolony/MESC_Firmware).

## To be clear, this would never happen without
* [MP2](https://github.com/badgineer/MP2-ESC), an open source motor controller from badgineer. 
* [MESC firmware](https://github.com/davidmolony/MESC_Firmware). 
* [Netzpfuscher's](https://github.com/Netzpfuscher/TTerm) incredible TTerm work

And a shout out to the PCB and PCBA sites: [pcbway.com](https://www.pcbway.com/) and [jlcpcb.com](https://jlcpcb.com/).

## Hardware
### Brain Board 
* Uses a teensy 4.0 and acts as the central controller
* Runs real-time control algorithms (e.g., balancing, walking gaits, velocity planning)
* Sends motor commands (e.g., desired torque, velocity, or position) over CAN bus
* Receives telemetry (velocity, torque, encoder angle) from motor controllers
* Integrates data from the IMU and other sensors
* Optionally logs data or interfaces with a host computer

### Motor Controller (with custom firmware)
* Executes low-level motor control (Field-Oriented Control)
* Supports:
  * Torque mode
  * Velocity mode
  * Position mode
* Reads angular position from the MT6701 encoder via SPI or PWM
* Computes:
  * Electrical angle for FOC
  * Velocity (from encoder delta over time)
  * Torque (via current sensing or estimation)
* Sends back telemetry via CAN (e.g., torque estimate, velocity, encoder angle)

### CAN Bus
* Full-duplex communication between Teensy and motor controllers
* Carries:
  * Commands: set_torque, set_velocity, enable_motor, zero_encoder, etc.
  * Telemetry: encoder position, estimated torque, velocity, fault codes
* Real-time performance with minimal latency
* Can support multiple motor controllers on the same bus

### MT6701 Encoder
* High-resolution magnetic rotary encoder (up to 14-bit)
* Measures rotor position for the BLDC
* Output via SPI, PWM, or ABI 
* Provides absolute angle, ideal for FOC and position tracking

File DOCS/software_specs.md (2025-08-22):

# MESC Brain Board Documentation

### Overview
The MESC Brain Board is a Teensy 4.0-based microcontroller platform responsible for high-level control of a balancing robot using BLDC motors. It interfaces with motor controllers over CAN, receives motion data from an MPU6050 IMU, accepts user commands from an RC transceiver via PWM, and communicates with an ESP32 over UART. The brain board includes status indicators such as LEDs and a speaker. 

This document just helping to think through firmware overview, and create really useful prompts for chatGPT.

#
### Hardware Interfaces / Peripherals
- Status indicators
  - Speaker
  - LEDs
    - Red
    - Green
- MPU6050 IMU
  - Interface: I2C
  - Tracks orientation and angular velocity
- PWM Inputs (from RC transceiver)
  - Used for manual control input
- CAN Bus (2 ports)
  - Connects to dual motor controllers (left and right)
  - Receives motor encoder, torque, velocity, and state information
  - Sends control commands (e.g. torque or velocity setpoints)
- UART to ESP32
  - ESP32 handles WiFi communications and remote telemetry
- UART to USB
  - term connection to computer

### Threads
- CAN
- Terminal
- User input
- Telemetry
- Speaker
- LEDs
- IMU

### Priority loop
- Calculating desired corrective torque/velocity
  - Process user input
  - Translating target to motor commands
- State management

### Control State Management
- CONTROL_IDLE
- CONTROL_ARMED
- CONTROL_MANUAL_RESET
- CONTROL_BALANCING
- CONTROL_TIPPED
- CONTROL_SHUTTING_DOWN

### Data structure for brain board
- Config
  - network name
  - node list
  - tipping_angle
  - max_turn
  - max_speed
  - ESC_num
- Raw input
  - PWM CH1-CH6
  - IMU I2C
  - User strings
  - UDP strings
- User_req
  - tilt_offset
  - speed
  - direction
  - left
  - right
  - P_input
  - I_input
  - D_input
- Params
  - obs_angle
  - obs_speed
  - tilt_offset
  - state
  - speed
  - direction
  - left
  - right
  - P_input
  - I_input
  - D_input
- Status
  - error
  - angle_initiated
- Error codes
  - TERM_FAILURE
  - TELEMETRY_FAILURE
  - IMU_FAILURE
  - RC_PWM_FAILURE
  - ANGLE_INIT_FAILURE
- LED1 control state
  - LED1_ON
  - LED1_FAST_BLINK
  - LED1_SLOW_BLINK
  - LED1_OFF
- LED2 control state
  - LED2_ON
  - LED2_FAST_BLINK
  - LED2_SLOW_BLINK
  - LED2_OFF
- Speaker control state
  - SPK_WARN1
  - SPK_WARN2
  - SPK_TRACK_BALANCE

### Data structure for each ESC
- Config
  - name 
  - node_id
  - pole_pairs
  - encoder_offset
  - max_amps
  - max_volts
  - min_volts
  - direction

- Raw input from controller, fast loop
  - adc1_2_req
  - speed
  - bus_volt
  - bus_current
  - motor_current
  - motor_voltage
  - FOC_angle

- Raw input from controller, slow loop
  - tmos
  - tmot
  - wanted: error_code

- Output to controller, fast loop
   - AMPS
   - DIRECTION

- Status
  - error

- Error codes
  - ESC_ERROR
  - ESC_OVERHEAT
  - ESC_OVERCURRENT
  - ESC_CAN
  - ESC_RESPONSE

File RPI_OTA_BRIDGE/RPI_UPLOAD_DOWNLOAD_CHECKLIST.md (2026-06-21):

# RPI Upload/Download Checklist

Reference commit: `c7eb63e1`
Date: 2026-06-21

## Goal

Implement a full run loop:

1. Desktop builds and uploads Teensy firmware via Pi bridge.
2. Teensy emits structured mock logs on USB Serial.
3. Pi listener captures and persists per-run artifacts.
4. Desktop waits for completion, fetches artifacts, and stores by run ID.
5. Offline analysis runs on desktop artifacts.

## Proposed Contracts

### Run ID

- Format: `YYYYMMDD_HHMMSS_<shortid>`
- Created on desktop before upload.
- Propagated everywhere:
  - firmware metadata (optional compile define)
  - Pi runtime paths
  - completion signal
  - fetched desktop archive path

### Serial Message Format (Teensy -> Pi)

Use line-delimited JSON for robust parsing:

```json
{"run_id":"20260621_101530_a1b2c3","seq":1,"t_ms":0,"level":"INFO","msg":"RUN_START"}
{"run_id":"20260621_101530_a1b2c3","seq":2,"t_ms":100,"level":"DATA","val":123}
{"run_id":"20260621_101530_a1b2c3","seq":999,"t_ms":5000,"level":"INFO","msg":"RUN_DONE"}
```

Rules:

- One JSON object per line.
- Include monotonic `seq` and `t_ms`.
- End run with `msg":"RUN_DONE"`.

### Completion Signal

Primary:

- Detect `{"msg":"RUN_DONE" ...}` on Pi listener.

Fallback:

- If no done marker within timeout, mark run `timed_out`.

## File Layout

### Pi paths

Base: `/home/<pi_user>/teensy_runs`

Per run:

- `<run_id>/meta.json`
- `<run_id>/serial_raw.log`
- `<run_id>/serial_parsed.jsonl`
- `<run_id>/status.json`

### Desktop paths

Base: `<project>/logs`

Per run:

- `<run_id>/meta.json`
- `<run_id>/status.json`
- `<run_id>/serial_raw.log`
- `<run_id>/serial_parsed.jsonl`

## Implementation Plan

### Phase 1: Pi serial listener service

1. Add Pi script `pi/listener/serial_listener.py`.
2. Resolve Teensy serial device (`/dev/ttyACM*`) with reconnect loop.
3. Read line-by-line with timestamping on Pi.
4. Persist `serial_raw.log` and parsed `jsonl`.
5. Set `status.json` transitions:
   - `starting` -> `running` -> `completed` or `timed_out` or `error`.
6. Add timeout support (for example 120s).

Acceptance:

- Listener survives disconnect/reconnect and keeps writing artifacts.

### Phase 2: Pi listener systemd integration

1. Add `pi/systemd/teensy-listener.service`.
2. Add install script `pi/scripts/install_listener_service.sh`.
3. Ensure run base directory permissions for non-root user.

Acceptance:

- `systemctl status teensy-listener.service` is active after reboot.

### Phase 3: Desktop run orchestration

1. Add desktop helper (new script) to:
   - create `run_id`
   - write run start marker on Pi (for example `current_run_id` file)
   - invoke `pio run -t bridge_send`
   - wait for Pi `status.json` terminal state
   - fetch artifacts via `scp`
2. Keep deterministic exit codes:
   - `0` success
   - `124` timeout
   - nonzero for transfer/flash/listener errors

Acceptance:

- One command executes full upload-run-fetch loop.

### Phase 4: Desktop analysis hook

1. Add a simple parser/report script over `serial_parsed.jsonl`.
2. Emit summary stats and plots-ready CSV if needed.

Acceptance:

- Analysis can run from local fetched artifacts without Pi access.

## Suggested Command Surface

From firmware project:

- Build + flash only:
  - `pio run -t bridge_send`

From orchestration script:

- Full cycle (build, flash, wait, fetch):
  - `./run_cycle.sh`

## Failure Modes To Handle

1. Teensy not found on serial device.
2. Flash succeeded but no serial output appears.
3. Partial JSON lines or malformed records.
4. No completion marker before timeout.
5. SSH/SCP transfer interruptions.
6. Stale previous-run files causing false success.

## Minimum Test Matrix

1. Happy path run completes with valid fetched logs.
2. Teensy unplugged before run start.
3. Teensy reset mid-run.
4. Completion marker intentionally omitted (timeout expected).
5. Network interruption during artifact fetch.

## First Coding Steps

1. Create `pi/listener/serial_listener.py` with JSONL + status writer.
2. Create `pi/systemd/teensy-listener.service` and installer script.
3. Create desktop orchestrator script to poll `status.json` and fetch artifacts.
4. Add README section with commands and troubleshooting.

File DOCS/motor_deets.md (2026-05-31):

## GBM5208-200T
- set par_ld 0.0054
- set par_lq 0.009 
- set par_r 8.5 Ω per phase

## GIM4305-10 Steadywin
- set par_ld 0.00014
- set par_lq 0.00021
- set par_r .65 
- set par_pp 14

## FLIPSKY 6215 KV170
- set par_ld 0.000015
- set par_lq 0.000022
- set par_pp 14
- set par_r  0.070000

## GL80 KV30
- set par_ld 0.00057 
- set par_lq 0.00082
- set par_pp 21
- set par_r  1.13
b ≈ 0.00138 N⋅m⋅s/rad

## GB36-2
- set par_ld 0.0049
- set par_lq 0.0088 
- set par_r 8.2
- set par_pp 7
b ≈ 0.00017 N·m·s/rad

## FLIPSKY_6382_190KV
- set par_ld 0.000015
- set par_lq 0.000022
- set par_r  0.0160f (no)
- set par_r  0.070000 (yes)
- set par_pp 7

## QS165 V2
- set par_ld 0.000042
- set par_lq 0.000065
- set par_pp 14 ?? 
- set par_r 0.006000

## Generic skateboard motor

36v 1600rpm skateboard motor, 
- No-load Current: 0.3A
- Maximum Current: 12A
- Speed: 15-20KM/h.
- KV ≈ 1600 / 36 ≈ 44.4 rpm/V
- set par_r 0.357
- set par_ld 0.000081
- set par_lq 0.000162

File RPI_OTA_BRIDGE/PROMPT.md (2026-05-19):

# Prompt Used To Generate This Project

I want to build a Raspberry Pi Zero 2 W Headless Teensy OTA Bridge in this workspace:
 /Users/owhite/balancing-robot-notes/RPI_OTA_BRIDGE

Implement the full project end to end without asking permission to create, edit, move, or copy files.

Project goals:
1. Raspberry Pi Zero 2 W acts as an OTA buffer and flasher for Teensy 4.0.
2. Desktop sends firmware to Pi with SCP.
3. Pi detects completed file transfer with Linux inotify via Python watchdog on_closed event.
4. Pi flashes Teensy using teensy_loader_cli and reports status back to desktop.

Technical requirements:
1. OS and provisioning assumptions
- Raspberry Pi OS Lite 64-bit.
- In Raspberry Pi Imager use hostname teensybridge.
- Access from desktop via teensybridge.local.
- SSH enabled, key auth preferred.
- Wi-Fi preconfigured.

2. Package and toolchain setup on Pi
- Install required packages with apt: build-essential, libusb-dev, git, python3-watchdog, openssh-client.
- Compile teensy_loader_cli from PJRC GitHub source on Pi for ARM compatibility.
- Install loader to /usr/local/bin/teensy_loader_cli.

3. Udev and USB permissions
- Create udev rules file at /etc/udev/rules.d/49-teensy.rules.
- Allow non-root access for PJRC USB vendor 16c0 (runtime and bootloader visibility).
- Reload udev rules in install flow.

4. Bridge service behavior
- Create bridge.py as a systemd-managed Python service.
- Watch directory: /home/<pi_user>/teensy_drops.
- Trigger only on watchdog on_closed events.
- Accept only .hex uploads.
- Flash command: teensy_loader_cli --mcu=TEENSY40 -w -s -v <file>.
- Capture stdout, stderr, exit code.
- Write full report to /home/<pi_user>/teensy_drops/last_upload_status.log.
- Move processed .hex to /home/<pi_user>/teensy_drops/processed with timestamp and ok/fail suffix.
- Do not reflash stale files on reboot.

5. Systemd
- Provide a persistent service unit.
- Service must work for custom Pi usernames, not hardcoded pi.
- Support configurable drop directory via environment variable TEENSY_DROP_DIR.

6. Desktop PlatformIO integration
- Provide desktop script upload_to_pi.py for PlatformIO post upload hook.
- Script copies firmware .hex to Pi via SCP.
- Script immediately tails remote status log over SSH.
- Script exits success only when EXIT_CODE=0 appears in log.
- On failure or timeout, print remote log and exit nonzero.
- Add required platformio.ini settings:
  extra_scripts = post:upload_to_pi.py
  upload_protocol = custom

7. Project structure and deliverables
- Create clean subdirectories for pi and desktop assets.
- Include install scripts for loader, udev, and bridge service.
- Include README with:
  - exact setup steps
  - verification commands
  - known failure modes and fixes
  - reproducibility note containing current short commit hash

8. Validation
- Run syntax checks for Python scripts.
- Ensure no obvious runtime path mismatches between scripts, service, and docs.
- Summarize created files and final run/test commands.

Important constraints:
1. Do not prompt me for file operation permission.
2. Prefer robust defaults for headless operation.
3. Keep output paths user-aware via <pi_user>.
4. Prioritize reliable hex upload flow for Teensy 4.0.

If anything is ambiguous, choose the implementation path most likely to work on Raspberry Pi OS trixie and explain the decision briefly in README.

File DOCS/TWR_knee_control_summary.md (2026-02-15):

# System Summary -- Two-Wheel Robot with Actuated Knee (MESC + Brain Board Architecture)

## ChatGPT Prompt Overview

I am building a two-wheeled balancing robot with an additional actuated
"knee" joint (similar in concept to Ascento). The knee is driven by a
BLDC motor through a planetary gearbox.

------------------------------------------------------------------------

## Architecture Overview

### Motor Control (Inner Loop)

-   Motor controllers run **MESC firmware**.
-   MESC provides:
    -   High-bandwidth **torque (current) control**
    -   Position and velocity feedback
    -   CAN bus communication
-   MESC does **not** reliably perform speed or position control
    internally.
-   It reports:
    -   Position (rad)
    -   Velocity (rad/s)
-   It accepts:
    -   Torque commands via CAN

### Supervisory Control (Outer Loop)

-   A custom **brain board (Teensy 4.0)** runs:
    -   High-level control logic
    -   State estimation
    -   Position control for the knee
-   Brain board communicates with MESC over **CAN bus**
-   Brain board sends torque commands
-   Brain board receives position and velocity feedback

System structure:

Brain Board (Teensy)\
↓ torque command (CAN)\
MESC (FOC current control)\
↓ phase currents\
Motor + Planetary Gearbox\
↑ position/velocity (CAN feedback)

------------------------------------------------------------------------

## Control Goal -- Knee Position Control

The knee joint must:

-   Move to a commanded position
-   Hold position reliably
-   Be reproducible (same final angle each time)
-   Work at low speeds
-   Be robust to gearbox friction and backlash

This is not a precision motion-control application. It just needs to
"work reliably."

------------------------------------------------------------------------

## Mechanical Characteristics of the Knee

-   BLDC motor
-   Planetary gearbox
-   Significant:
    -   Static friction (stiction)
    -   Coulomb friction
    -   Possible backlash
-   Likely asymmetric torque requirements:
    -   More torque required to **raise** (against gravity)
    -   Less torque required to **lower**
    -   May require active braking when lowering

------------------------------------------------------------------------

## Position Control Strategy (Implemented on Brain Board)

Position control is implemented on the brain board using torque mode on
MESC.

Control law:

τ = Kp (θ_ref − θ) − Kd ω + τ_friction

Where:

-   Kp = position gain
-   Kd = damping gain
-   θ_ref = target position
-   θ = measured position
-   ω = measured velocity

------------------------------------------------------------------------

## Friction Compensation (Required)

Because of the planetary gearbox, friction compensation is mandatory:

### Static Friction Compensation

When position error exists but velocity ≈ 0:

τ_stiction · sign(error)

### Coulomb Friction Compensation

During motion:

τ_c · sign(ω)

### Optional Viscous Term

b · ω

------------------------------------------------------------------------

## Backlash Handling

To improve reproducibility:

-   Always approach the final position from the same direction
-   Or overshoot slightly and return to the target

------------------------------------------------------------------------

## Key Design Decisions

-   Do not modify MESC to add position control.
-   Use MESC purely as:
    -   High-speed torque controller
    -   Sensor reporting device
-   Implement all position logic on the brain board.
-   Run outer loop at \~200--500 Hz over CAN.

------------------------------------------------------------------------

## What We Care About

-   Reproducible final position
-   Stable position hold
-   No oscillation
-   No runaway when lowering
-   Minimal complexity

We are not optimizing for:

-   High-speed trajectory control
-   Precision industrial servo performance
-   Perfect speed regulation

------------------------------------------------------------------------

## Current Status

-   Torque control over CAN works.
-   Position and velocity feedback from MESC works.
-   Mechanical damping has been experimentally measured for other
    motors.
-   Next step: implement robust low-speed knee position hold using
    torque mode + friction compensation.
-   You may use other strategies than what was described in the position control section

------------------------------------------------------------------------

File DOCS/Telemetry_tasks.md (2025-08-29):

# Balancing Robot Telemetry Checklist

This checklist outlines staged plotting and logging goals for developing a Teensy + ESP32 balancing robot.  
Stages progress from low-level comms timing to full closed-loop balancing performance.

---

## Stage 0 — Comms & Timing (no control yet)
**Goal:** prove there’s no jitter and rates are correct.

- Loop period (`dt` in ms) vs time  
  - Histogram of dt  
  - Min/mean/max
- CAN message rate (frames/s) per ID  
  - Rolling count by ID  
  - Utilization % (frames/s × avg bytes / bus bitrate)
- UDP/Wi-Fi inter-arrival time (ms) & loss  
  - Sequence number for packet loss detection  
  - Latency estimate (TX vs RX timestamps)
- Queue depths / buffers (TX, RX)

---

## Stage 1 — Sensors alive & sane
**Goal:** confirm IMU/encoders are clean, oriented, and scaled.

- IMU accel & gyro (3 axes) vs time  
- Wheel/encoder position & velocity  
- Battery voltage & current  
- Noise snapshot (PSD / spectrum of gyro Z or tilt rate)

---

## Stage 2 — State estimation (if using a filter)
**Goal:** validate your state vector before closing the loop.

- Tilt angle (measured vs estimated) & tilt rate  
- Innovation/residuals (measured − predicted)  
- Confidence metrics (variance/covariance if available)

---

## Stage 3 — Open-loop actuator tests (wheels off-ground)
**Goal:** verify commands map to motion.

- Commanded motor effort vs measured wheel speed  
- Step response plots (speed vs time)  
- Current vs effort (torque constant check)

---

## Stage 4 — Closed-loop balancing at fixed height
**Goal:** bring it up gently and verify stability margins.

- Strip chart: tilt angle, tilt rate, wheel velocity, (optionally) position drift  
- Control inputs `u` (per motor) vs time  
- Optional: Kx terms breakdown (e.g., `k_theta*theta`, `k_dtheta*theta_dot`, etc.)  
- Settle time & overshoot for small disturbances

---

## Stage 5 — Robustness & performance
**Goal:** quantify comfort margins.

- Disturbance response (gentle pushes): angle, u, recovery time  
- Position creep/drift vs time at standstill  
- Motor/driver temperatures vs effort  
- Battery voltage sag vs thrust bursts

---

## Nice quality-of-life plots (any stage)

- Rolling stats panel: dt mean/std, packet loss %, CAN util %, CPU %  
- Event markers: log/annotate events (enable control, step, push)  
- Alarm flags: dt > threshold, loss > threshold, queue > N

---

## Suggested targets (ballpark)

- Control loop dt: mean ~1.0–2.0 ms (500–1000 Hz), std dev < 0.1–0.2 ms  
- CAN command/telemetry: 250–500 Hz per critical topic, bus util < ~40%  
- UDP loss: < 0.5%, inter-arrival jitter < 5–10 ms typical  
- Tilt at standstill: < 0.5–1.0° RMS; recovery < 0.3–0.5 s after a small bump  
- Actuator clipping: rare in steady state; visible only on disturbances

---

## Minimal telemetry packet schema (JSON-style)

```json
{
  "t": 12345678,
  "seq": 42,
  "dt": 0.002,
  "can_rx_counts": { "0x101": 500, "0x102": 250 },
  "imu": { "ax":0.0,"ay":0.0,"az":9.8,"gx":0.01,"gy":0.0,"gz":0.0 },
  "enc": { "pos":1234, "vel":12.3 },
  "state": { "theta":0.05,"theta_dot":-0.01,"v":0.1 },
  "u": { "left":0.2, "right":0.2 },
  "batt": { "V":23.8,"I":1.2 },
  "flags": { "clip":false, "overtemp":false, "loss":0 }
}

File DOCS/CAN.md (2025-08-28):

# Intro
## CAN POS/VEL, Telemetry, and Scheduling — Project Synopsis
- Goal: (Teensy 4.0 “brain board” & ESCs over CAN)
- Deterministic control at 1 kHz on Teensy.
- Low-jitter I/O: CAN setpoints and fast encoder feedback for balancing.
- Implement: control-plane (fast) vs telemetry-plane (slow).

## Control plane
- Control-plane (fast, 500–1000 Hz).
- Runs on Teensy: IMU + estimator + LQR/PID at 1 kHz.
- Sends setpoints (torque/velocity/position) to ESCs each tick.
- Reads high-rate encoder pos/vel from ESCs (new fast stream; see below).

## Why 500 Hz (or 1 kHz) Makes Sense
- 2 kHz sampling in a classic LQR balancing system ([Park et al.](https://link.springer.com/article/10.1007/s10015-011-0897-9?utm_source=chatgpt.com)) establishes an upper benchmark—suggesting that balance control benefits from high-frequency updates.
  - See also: [Ref1](https://indusedu.org/pdfs/IJREISS/IJREISS_3094_97729.pdf?utm_source=chatgpt.com) and [Ref2](https://www.mdpi.com/1424-8220/25/4/1056?utm_source=chatgpt.com)
- Running at 500–1000 Hz provides plenty of bandwidth to implement LQR-based stabilization effectively—while being manageable for embedded systems like Teensy + ESCs.

## There already is a telemetry-plane (slow, ~10–50 Hz)
- Useful for monitoring/logging: Vbus, Ibus, eHz, Idq/Vdq, state, etc.
- Will not be used for balancing
- MESC “fast” telemetry is actually ~10 Hz (every 100 ms)
- Not for stabilization; too slow for 1 kHz balancing.

## Bus Load Reality Check (CAN 2.0 @ 1 Mb/s)
- 2 ESCs × 1 kHz commands (~128 b per frame) ≈ 256 kb/s.
- 2 ESCs × 1 kHz POS/VEL ≈ 256 kb/s.
- Total ≈ 50% bus load (before additional telemetry). At 500 Hz POS/VEL, ≈ 25%.

## Commands vs Telemetry (Priority)
- Commands: highest priority, periodic/event-driven; send right after compute.
  - Coalesce (latest-wins) if back-pressured; never block.
- Telemetry: lower priority, best-effort; okay to drop when bus busy.
- Fast POS/VEL: own tiny task on ESC; independent of slow telemetry.

# Inserting CAN code into MESC
## From looking at `MESC_F405RG/MESC_F405RG.ioc`:
- PWM frequency = ~41 kHz
- MESC_ADC_IRQ_handler() execution rate = ~82 kHz
- `fastLoop()` runs at ~82 kHz

## Sending encoder position and motor velocity over CAN
- Putting it inside `fastLoop()` (82 kHz ISR) is not appropriate.
- It risks jitter in a time-critical ISR.
- The correct place is a separate FreeRTOS task.
- Schedule the task at 500–1000 Hz.
- Use `vTaskDelayUntil()` for cadence.
- Enqueue one frame each tick.
- TX handled by `TASK_CAN_tx`.
- This ensures no extra jitter in FOC timing.

## MESC code reads encoder counts (TIMx->CNT) every ISR
- It computes difference in counts (`diff`) from the previous sample.
- Scales that by encoder resolution and sampling period to estimate velocity.
- The logic looks like this (simplified):

```c
diff = new_count - last_count;
_motor->FOC.mechanical_angle += diff * (2π / encoder_ticks_per_rev);
_motor->FOC.mechanical_omega = diff * (2π / encoder_ticks_per_rev) * sample_rate;
```

- MESC normalizes by encoder CPR (counts per revolution) and multiplies by the loop rate (82 kHz ISR).
  - As a result:
    - `mechanical_angle` → radians (can wrap or accumulate).
    - `mechanical_omega` → radians/second (rad/s).
  - Therefore `_motor->FOC.mechanical_omega` reflects angular velocity of the rotor/wheel in physical units.

## Implementation plan

### 1. Current CAN tasks (in `task_can.c`)
```c
xTaskCreate(TASK_CAN_rx,        "task_rx_can", 256, (void*)port, osPriorityAboveNormal, &handle->rx_task_handle);
xTaskCreate(TASK_CAN_tx,        "task_tx_can", 256, (void*)port, osPriorityAboveNormal, &handle->tx_task_handle);
xTaskCreate(TASK_CAN_telemetry, "can_metry",   256, (void*)port, osPriorityAboveNormal, NULL);
```

### 2. New FreeRTOS Task (in `task_can.c`)
```c
#ifdef POSVEL_PLANE
static void TASK_CAN_posvel(void *arg) {
    TASK_CAN_handle *h = (TASK_CAN_handle*)arg;
    const TickType_t period = pdMS_TO_TICKS(1000 / POSVEL_HZ);
    TickType_t last = xTaskGetTickCount();

    for (;;) {
        TASK_CAN_telemetry_posvel(h);
        vTaskDelayUntil(&last, period ? period : 1);
    }
}
#endif
```

Add alongside the other tasks:
```c
#ifdef POSVEL_PLANE
xTaskCreate(TASK_CAN_posvel, "can_posvel", 256, (void*)port, osPriorityAboveNormal, NULL);
#endif
```

### 3. New CAN ID (in `can_ids.h`)
```c
#ifdef POSVEL_PLANE
#define CAN_ID_POSVEL            0x2D0   // new high-rate position/velocity ID
#endif
```

### 4. Feature Toggle (in project header)
Add to one of these headers:
- `MESC_F405RG/Core/Inc/main.h`
- `MESC_F405RG/Core/Inc/MP2_V0_1.h`
- `MESC_F405RG/Core/Inc/MESC_F405.h`

```c
#define POSVEL_PLANE 1
```

### 5. Telemetry Function (in `MESCinterface.c`)
```c
#ifdef POSVEL_PLANE
void TASK_CAN_telemetry_posvel(TASK_CAN_handle *handle) {
    MESC_motor_typedef *motor_curr = &mtr[0];
    TASK_CAN_add_float(handle, CAN_ID_POSVEL, CAN_BROADCAST,
                       motor_curr->FOC.mechanical_angle,
                       motor_curr->FOC.mechanical_omega,
                       0);
}
#endif
```

## Receiving CAN commands from Teensy
- MESC already spawns `TASK_CAN_rx` at high priority (`osPriorityAboveNormal`) to process incoming frames.
- Torque setpoint commands are mapped to CAN_ID_IQREQ, which updates `_motor->FOC.Idq_req.q`.
- `_motor->FOC.Idq_req.q` is a signed float:
  - Positive → forward torque
  - Negative → reverse torque
- FOC loop (82 kHz) consumes this value each cycle; if no new frame arrives, it reuses the last command.
- Teensy should send one new command per 1 kHz control tick, ensuring ESC always has a fresh reference.

# Teensy side considerations
## Teensy Architecture (not using RTOS)
- Timing & Priority
  - IntervalTimer ISR: sets `control_due` + timestamp; no math in ISR.
  - Superloop priority order:
    - If `control_due` → run `control_step()` (compute + enqueue CAN command).
    - `Can.events()` → RX callback → drain/parse ring.
    - Low-priority chores: LEDs (state machine), pushbutton debounce, serial pump.

- CAN on Teensy (FlexCAN_T4)
  - Use `onReceive()` + tiny RX callback that copies frames into a ring buffer.
  - Parse in loop (non-blocking), update snapshots for control to read.
  - Commands: enqueue and send immediately (or via a small TX pump).
  - Do not block or print inside `control_step()`.

## CAN Framing & Decoding
- MESC ID Scheme (Extended 29-bit)
  - ESC packs {msg_id, sender, receiver} into the extended ID.
  - Working assumption:

```c
msg_id: bits 28..16 (13 b), sender: 15..8 (8 b), receiver: 7..0 (8 b; 0=broadcast).

static inline uint32_t mesc_pack_id(uint16_t msg, uint8_t snd, uint8_t rcv) {
  return ((uint32_t)(msg & 0x1FFF) << 16) | ((uint32_t)snd << 8) | rcv;
}
static inline void mesc_unpack_id(uint32_t id, uint16_t &msg, uint8_t &snd, uint8_t &rcv) {
  msg = (id >> 16) & 0x1FFF; snd = (id >> 8) & 0xFF; rcv = id & 0xFF;
}
```

### Key IDs
- Existing telemetry (slow): **CAN_ID_SPEED**, **CAN_ID_BUS_VOLT_CURR**, **CAN_ID_MOTOR_CURRENT**, **CAN_ID_MOTOR_VOLTAGE**, **CAN_ID_ADC1_2_REQ**, **CAN_ID_STATUS**.
- Control/utility: **CAN_ID_PING** (8-byte ASCII name, ~1 Hz), **CAN_ID_CONNECT**, **CAN_ID_TERMINAL**.
- New (proposed): **CAN_ID_POSVEL** (8 bytes) → pos, vel at 500–1000 Hz.

### Payloads
- Helpers in ESC send 8-byte payloads as 2×float32 or 2×uint32.
- Likely little-endian (STM32 default). Teensy decodes with memcpy.

```c
static inline void parse_two_floats(const uint8_t *b, float &a, float &c) {
  uint32_t u0 = b[0]|(b[1]<<8)|(b[2]<<16)|(b[3]<<24);
  uint32_t u1 = b[4]|(b[5]<<8)|(b[6]<<16)|(b[7]<<24);
  memcpy(&a,&u0,4); memcpy(&c,&u1,4);
}
```

### Teensy handling of POS/VEL
RX path:
- FlexCAN RX callback → ring push → main loop parse → pos/vel snapshot (per ESC) with timestamp/seq.

```c
struct PosVel { float pos_rad, vel_rad_s; uint32_t t_us, seq; };
volatile PosVel esc_posvel[2];

void handle_mesc(const CAN_message_t &m) {
  uint16_t id; uint8_t snd, rcv; mesc_unpack_id(m.id, id, snd, rcv);
  if (rcv != 0 && rcv != MY_NODE) return;
  if (id == CAN_ID_POSVEL && m.len == 8) {
    float p,v; parse_two_floats(m.buf, p, v);
    uint8_t i = (snd == LEFT_ESC_ID) ? 0 : 1;
    esc_posvel[i].pos_rad = p; esc_posvel[i].vel_rad_s = v;
    esc_posvel[i].t_us = micros(); esc_posvel[i].seq++;
  }
}
```

In `control_step()`, copy latest snapshot into local variables. Optionally extrapolate:

```
pos_est = pos + vel * dt; // dt = time since RX
```

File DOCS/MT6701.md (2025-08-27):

### MT6701 Encoder
* High-resolution magnetic rotary encoder (up to 14-bit)
* Measures rotor position for the BLDC
* Output via SPI, PWM, or ABI 
* Provides absolute angle, ideal for FOC and position tracking

When programming the board be sure to do it at +5V over I2C. Suppose you bought a MT6701 board and you wanted to determine its mode setting. Use this with a arduino-based controller:
```
#include <Wire.h>

#define MT6701_ADDR 0x06  

void setup() {
  Serial.begin(115200);
  Wire.begin();
  Wire.setClock(400000);

  delay(100);

}

void loop() {

  delay(1000);

  int modeByte = readRegister(0x38);
  if (modeByte < 0) {
    Serial.println("Failed to read register 0x38.");
    return;
  }

  int outMode = modeByte & 0b11;       // Bits 1:0
  int uvwRes  = (modeByte >> 4) & 0b111; // Bits 6:4

  Serial.print("OUT_MODE bits: ");
  Serial.println(outMode, BIN);

  switch (outMode) {
    case 0b00:
      Serial.println("🟢 MT6701 is in ABZ mode (quadrature encoder output).");
      break;
    case 0b01:
      Serial.println("🟡 MT6701 is in PWM or Analog output mode.");
      break;
    case 0b10:
      Serial.print("🔵 MT6701 is in UVW (commutation) mode. Pole pairs setting: ");
      Serial.println(uvwRes + 1);
      break;
    case 0b11:
      Serial.println("🔴 Invalid or reserved OUT_MODE value (0b11).");
      break;
  }
}

oid writeRegister(uint8_t reg, uint8_t val) {
  Wire.beginTransmission(MT6701_ADDR);
  Wire.write(reg);
  Wire.write(val);
  Wire.endTransmission();
}

int readRegister(uint8_t reg) {
  Wire.beginTransmission(MT6701_ADDR);
  Wire.write(reg);
  if (Wire.endTransmission(false) != 0) {
    return -1;
  }

  Wire.requestFrom(MT6701_ADDR, 1);
  if (Wire.available() < 1) {
    return -1;
  }

  return Wire.read();
}
```

Here's code for setting the mode:
```
#include <Wire.h>
#define MT6701_ADDR 0x06  // Change if your MT6701 has a different address

// ---------- I2C helper ----------
void writeRegister(uint8_t reg, uint8_t val) {
  Wire.beginTransmission(MT6701_ADDR);
  Wire.write(reg);
  Wire.write(val);
  Wire.endTransmission();
}

int readRegister(uint8_t reg) {
  Wire.beginTransmission(MT6701_ADDR);
  Wire.write(reg);
  if (Wire.endTransmission(false) != 0) return -1;
  Wire.requestFrom(MT6701_ADDR, 1);
  if (Wire.available() < 1) return -1;
  return Wire.read();
}

// ---------- Setup ----------
void setup() {
  Serial.begin(115200);
  Wire.begin();
  Wire.setClock(400000);

  Serial.println("Programming MT6701 to 1024 PPR...");

  // 1. Set ABZ_RES to 0x3FF (1023 decimal => 1024 PPR)
  uint16_t abz_res = 0x03FF;
  writeRegister(0x30, (abz_res >> 8) & 0x03); // bits 9:8
  writeRegister(0x31, abz_res & 0xFF);        // bits 7:0

  // 2. EEPROM program sequence
  writeRegister(0x09, 0xB3); // EEPROM key
  writeRegister(0x0A, 0x05); // EEPROM command

  // 3. Wait >600 ms for EEPROM write
  delay(1000);

  Serial.println("EEPROM programmed. Power-cycle MT6701 to apply changes.");
  Serial.println("Now reading back PPR every second...");
}

// ---------- Loop: verify every second ----------
void loop() {
  int r29 = readRegister(0x29); // ABZ/UVW select
  int r30 = readRegister(0x30); // upper bits of PPR
  int r31 = readRegister(0x31); // lower bits of PPR

  if (r29 < 0 || r30 < 0 || r31 < 0) {
    Serial.println("I2C read error");
  } else {
    bool abz_selected = ((r29 & (1 << 6)) == 0); // 0 = ABZ
    uint16_t abz_code = ((r30 & 0x03) << 8) | (uint8_t)r31;
    uint16_t abz_ppr  = abz_code + 1;            // encoded as value+1

    Serial.print("ABZ selected: ");
    Serial.println(abz_selected ? "YES" : "NO");

    Serial.print("ABZ PPR (pulses/rev): ");
    Serial.println(abz_ppr);

    Serial.print("Quadrature counts/rev (4x): ");
    Serial.println((uint32_t)abz_ppr * 4);
    Serial.println();
  }

  delay(1000); // read once per second
}
 ```

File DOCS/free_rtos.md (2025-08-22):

# FreeRTOS Hardware considerations

According to ChatGPT FreeRTOS is appropriate to use for this project if you structure it so the balancing loop has rock-solid timing. FreeRTOS is a good fit for a balancing robot on Teensy 4.0 provided the balance loop is time-triggered via a hardware timer and isolated from blocking work. Use RTOS tasks for everything else. This gives you clean structure now and headroom to add gaits, logging, and comms without jeopardizing stability.

## The safest pattern is a hybrid:
- Put the 1 kHz (or whatever) balance/control loop on a hardware timer interrupt (or a highest-priority, timer-released task with bounded jitter).
- Run everything else (CAN comms, logging, UI, host link) as lower-priority FreeRTOS tasks that communicate with the control loop via lock-free mailboxes/queues or double buffers.

## Why this works well for a balancing robot
- Clear separation of concerns (control, comms, logging).
- Priority scheduling so background work can’t starve the control path.
- Clean inter-task comms (queues/semaphores) instead of ad-hoc globals.
- Easier to scale as you add features (e.g., gait modes, host RPC).

## Risks & how to avoid them

- Jitter: Don’t rely on a round-robin loop() or a normal RTOS tick to schedule the control law. Use a hardware timer to trigger it (ISR) or a direct-to-task notification that wakes a highest-priority task. Target < ~50–100 µs jitter for a 1 kHz loop.
- Blocking: Never block in the control loop (no printf, no I/O). Push data to a queue/ring buffer and let a lower-priority task handle I/O.
- Interrupt latency: Keep ISRs short; defer work to tasks via xQueueSendFromISR()/vTaskNotifyGiveFromISR().

## Practical layout on Teensy 4.0 (Cortex-M7 @ 600 MHz)
- Timer: Use a PIT/GPT timer at 1 kHz.

## Control loop recommended for RTOS style: timer ISR notifies a highest-priority task (no time slicing, no blocking) that executes the control step. Measure jitter; if acceptable, keep it.

- Tasks (descending priority):
- control_task (woken by timer notification; priority highest)
-sensor_fusion_task / IMU (reads/filters IMU; updates a double buffer)
- can_task (parses RX, sends TX; uses queues to/from control)
- logger_task (SD/serial/USB; batch writes to avoid I/O stalls)
- ui/host_task (CLI/telemetry to PC)

## Data movement patterns (safe & fast)
- Double buffers for IMU and setpoints: producer writes buffer A while control reads buffer B; swap with an atomic flag.
- Queues for CAN & logging: xQueueSendFromISR() in ISRs; xQueueReceive() in worker tasks.
- No locks in control: avoid mutexes in the control path.

## Tuning tips
- Set a watchdog and kick it in the control path.
- Give the control task a generous stack (math + FPU).
- Keep the RTOS tick rate modest (e.g., 1 kHz is fine, but don’t depend on it for control timing).
- Measure jitter with a scope (GPIO toggle at loop entry/exit). Adjust priorities/IRQs until it’s within your budget.

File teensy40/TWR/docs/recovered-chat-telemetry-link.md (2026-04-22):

# Recovered Chat: telemetry_link work

If the Codex thread UI spins, use this recovered reference.

## Original thread metadata
- Thread name: `Review Serial1 output from balance_T`
- Thread id: `019cca67-dd9d-7e53-8b38-ba13372f8b98`
- Transcript file:
  `/Users/owhite/.codex/sessions/2026/03/07/rollout-2026-03-07T17-25-30-019cca67-dd9d-7e53-8b38-ba13372f8b98.jsonl`

## Key result from that chat (2026-04-21 around 23:11 UTC)
- Added `src/telemetry_link.h` and `src/telemetry_link.cpp`
- Wired telemetry into:
  - `src/main.h`
  - `src/main.cpp`
  - `src/balance_TWR_mode.cpp`
- Transport design summary from that thread:
  - fixed-size 64-byte packet
  - CRC16-CCITT + footer `0xDEAD`
  - SPSC ring buffers for fast/event channels
  - non-blocking UART pump (`availableForWrite`)
  - event-priority overflow policy

## Direct extraction commands
Run these from a terminal to pull the exact final message lines:

```bash
rg -n "Implemented\. We now have a dedicated, non-blocking Teensy→ESP32 telemetry link|telemetry_link\.h|telemetry_link\.cpp|TELEM_LINK_CFG" \
  /Users/owhite/.codex/sessions/2026/03/07/rollout-2026-03-07T17-25-30-019cca67-dd9d-7e53-8b38-ba13372f8b98.jsonl
```

```bash
sed -n '6558,6565p' \
  /Users/owhite/.codex/sessions/2026/03/07/rollout-2026-03-07T17-25-30-019cca67-dd9d-7e53-8b38-ba13372f8b98.jsonl
```

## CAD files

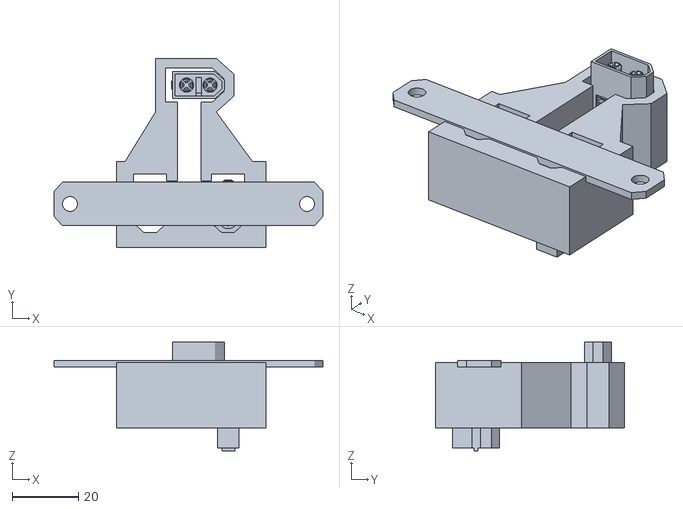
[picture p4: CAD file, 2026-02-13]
modeling/data/GL80/battery_connector.stl
81.3 x 57.3 x 32.8

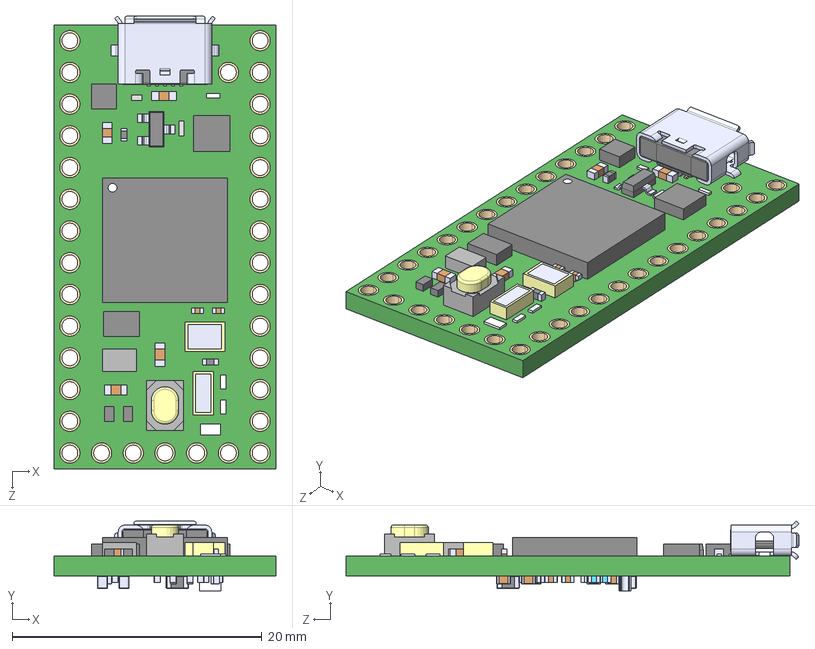
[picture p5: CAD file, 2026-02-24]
PCBs/brainboardV1.6/DEV-15583/DEV-15583.step
17.8 x 5.58 x 36.3 mm
DEV-15583 board
C5-C18 (0.55mm)
C20-C24 (0.65)
R1-R3 (0.4inch)_1269AS-H-3R3M=P2
L1^DEV-15583 ASS
C x 2
C2

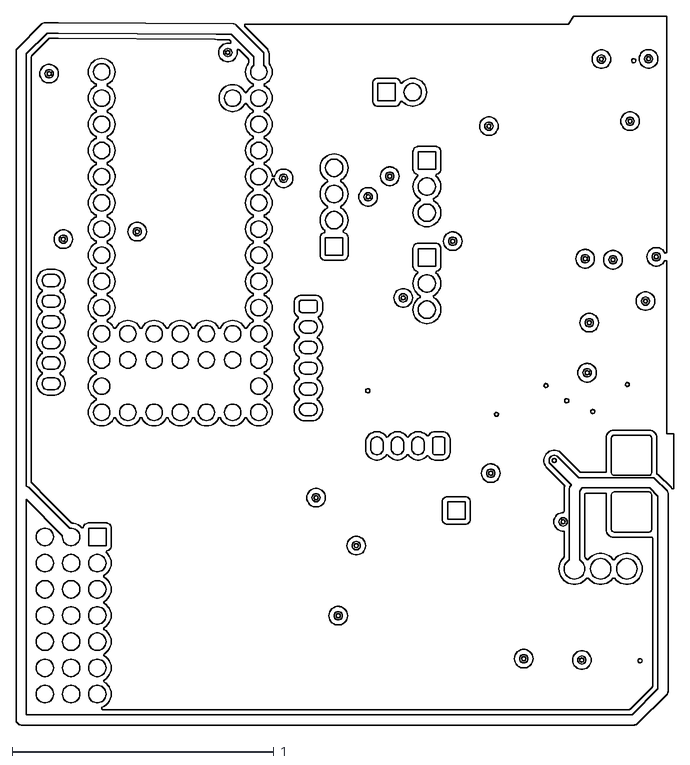
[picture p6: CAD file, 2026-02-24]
PCBs/brainboardV1.6/DXFs/MESC_brain_board-In2_Cu.dxf
2.51 x 2.71

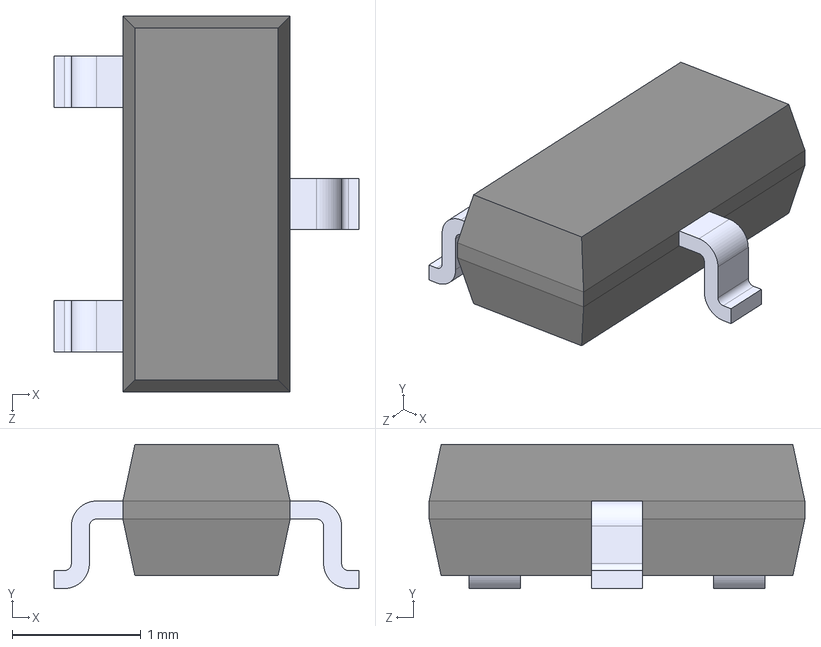
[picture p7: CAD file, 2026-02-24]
PCBs/brainboardV1.6/SM24CANB-02HTG/SM24CANB-02HTG.step
2.37 x 1.12 x 2.92 mm

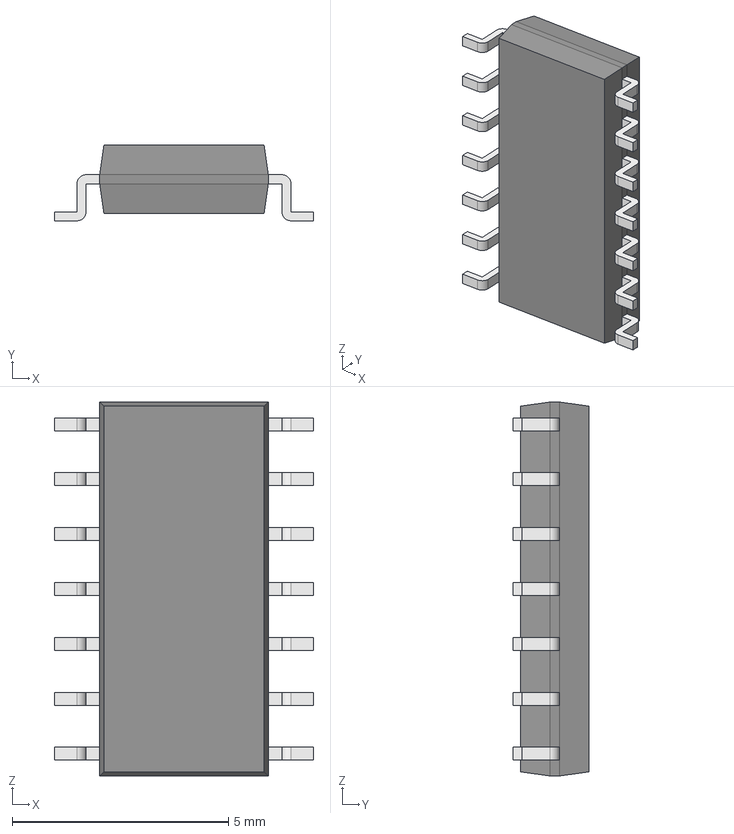
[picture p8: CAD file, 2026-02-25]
PCBs/brainboardV1.6/SN74LVC14AD/SN74LVC14AD.step
6.00 x 1.75 x 8.65 mm
Body001 (Mirror #1) x 7
XY-plane x 12
X-axis x 12

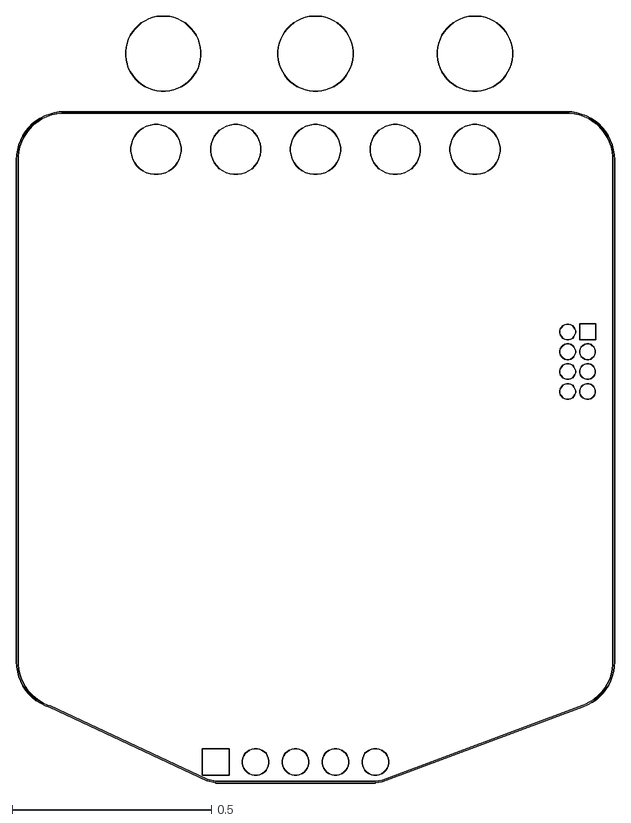
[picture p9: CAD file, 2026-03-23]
PCBs/moteus_adaptor/moteus_adaptor-Edge_Cuts.dxf
1.50 x 1.92

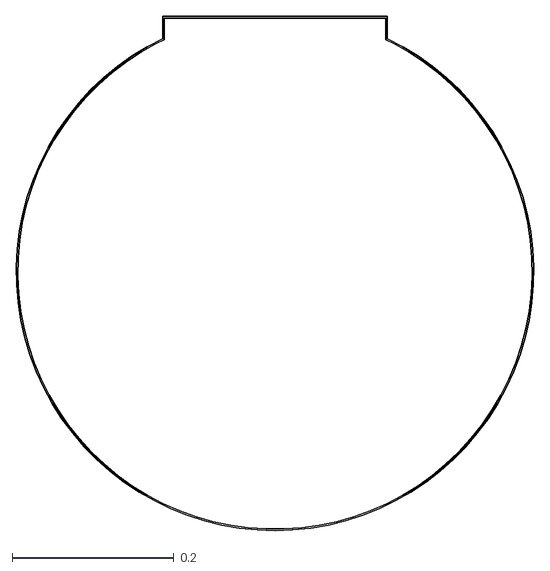
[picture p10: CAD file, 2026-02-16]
PCBs/MT6701_12mm/DXF/MT6701_ENCODER-Edge_Cuts.dxf
0.64 x 0.636

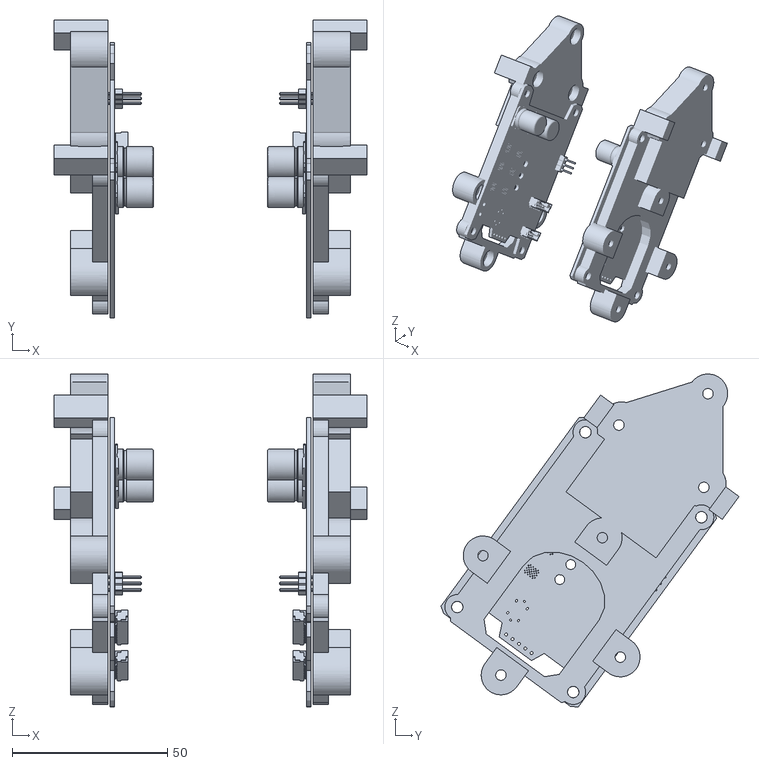
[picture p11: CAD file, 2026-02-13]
modeling/data/GL80/pcb_encoder_mounts.stl
100.7 x 96.0 x 107.2

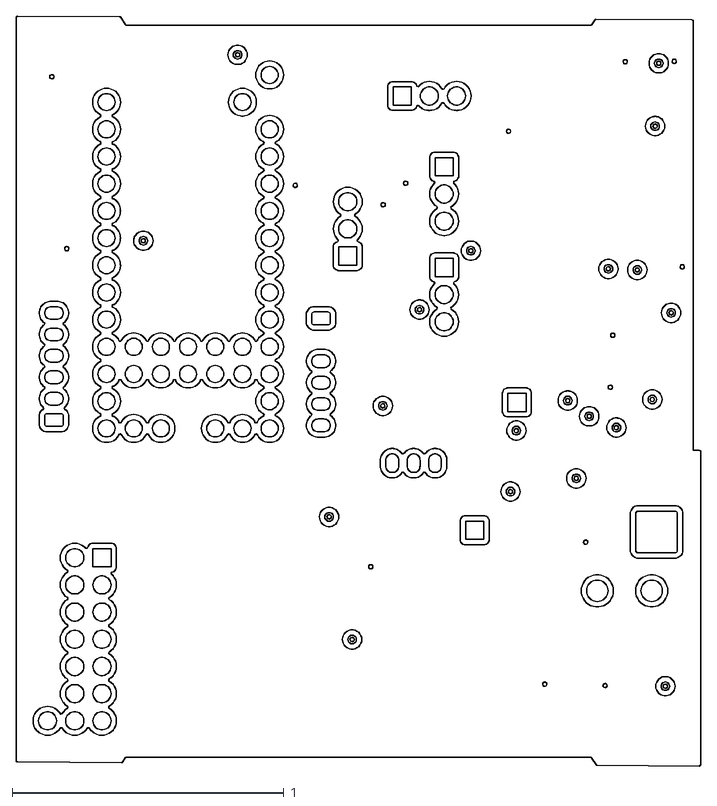
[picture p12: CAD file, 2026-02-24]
PCBs/brainboardV1.6/DXFs/MESC_brain_board-In1_Cu.dxf
2.52 x 2.76

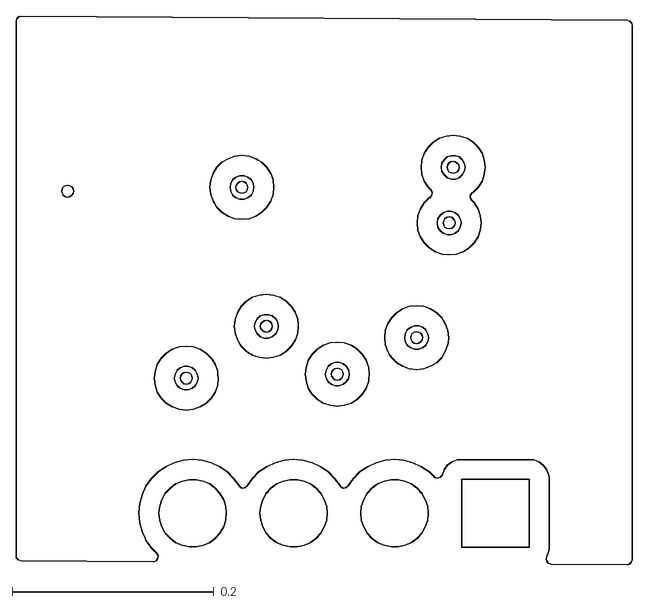
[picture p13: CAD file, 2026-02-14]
PCBs/DXF/MT6701_ENCODER-In2_Cu.dxf
0.61 x 0.543

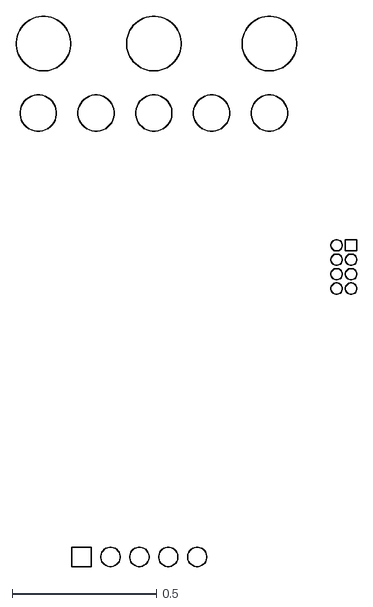
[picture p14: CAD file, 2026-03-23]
PCBs/moteus_adaptor/moteus_adaptor-F_Cu.dxf
1.18 x 1.90

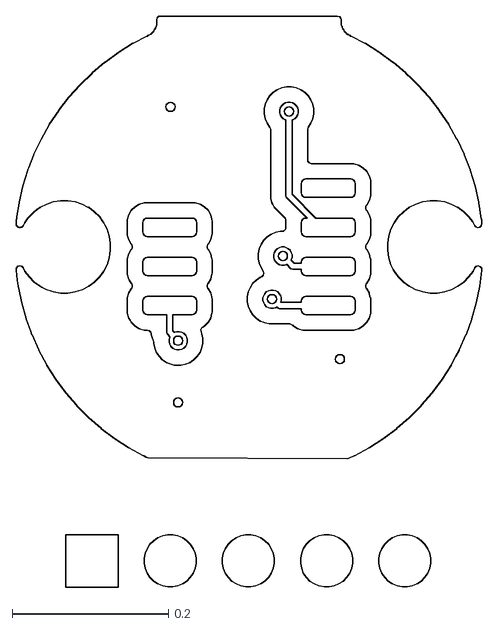
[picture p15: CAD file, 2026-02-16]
PCBs/MT6701_12mm/DXF/MT6701_ENCODER-B_Cu.dxf
0.596 x 0.73

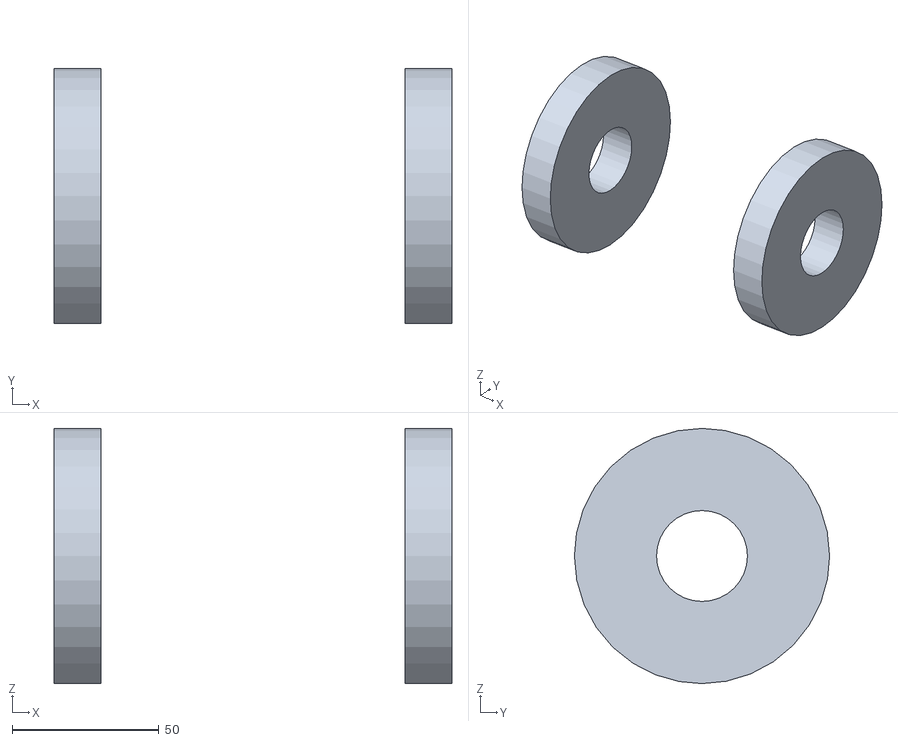
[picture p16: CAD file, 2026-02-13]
modeling/data/GL80/rotors.stl
135.7 x 87.0 x 87.0

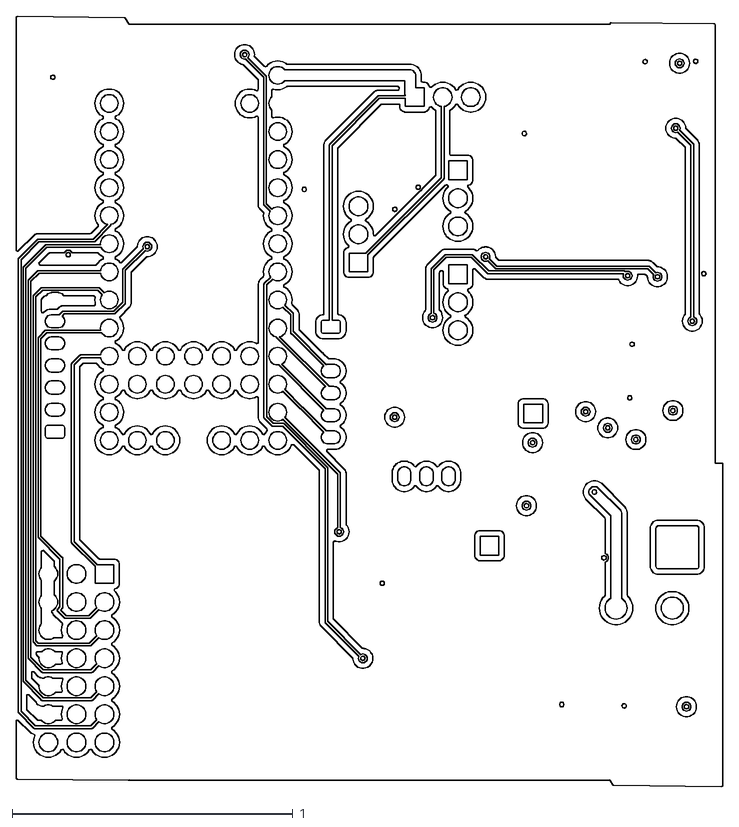
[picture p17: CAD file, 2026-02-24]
PCBs/brainboardV1.6/DXFs/MESC_brain_board-B_Cu.dxf
2.52 x 2.74

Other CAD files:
PCBs/moteus_adaptor/moteus_adaptor-B_Cu.dxf
PCBs/MT6701_12mm/DXF/outline.dxf
modeling/data/GL80/brain_board.stl
CAD/Farm-All Tractor rusty obj.3dm
CAD/GB36-2_flat.3dm
CAD/Untitled.3dm
CAD/scrap.3dm
PCBs/DXF/MT6701_ENCODER-B_Cu.dxf
PCBs/DXF/MT6701_ENCODER-B_Mask.dxf
PCBs/DXF/MT6701_ENCODER-B_Silkscreen.dxf
PCBs/DXF/MT6701_ENCODER-Edge_Cuts.dxf
PCBs/DXF/MT6701_ENCODER-F_Cu.dxf
PCBs/DXF/MT6701_ENCODER-F_Mask.dxf
PCBs/DXF/MT6701_ENCODER-F_Paste.dxf
PCBs/DXF/MT6701_ENCODER-F_Silkscreen.dxf
PCBs/MT6701_12mm/DXF/MT6701_ENCODER-B_Mask.dxf
PCBs/MT6701_12mm/DXF/MT6701_ENCODER-B_Paste.dxf
PCBs/MT6701_12mm/DXF/MT6701_ENCODER-B_Silkscreen.dxf
PCBs/MT6701_12mm/DXF/MT6701_ENCODER-F_Cu.dxf
PCBs/MT6701_12mm/DXF/MT6701_ENCODER-F_Mask.dxf
PCBs/MT6701_12mm/DXF/MT6701_ENCODER-F_Paste.dxf
PCBs/MT6701_12mm/DXF/MT6701_ENCODER-F_Silkscreen.dxf
PCBs/MT6701_12mm/outline.3dm
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

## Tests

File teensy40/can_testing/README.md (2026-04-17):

# STM32F405 CAN Testing Plan

This workspace is a standalone CAN test effort for:
- Teensy 4.0 (test peer / traffic generator / logger)
- STM32F405 pill (bare-minimum PCB, fresh firmware)

This work is intentionally separate from `MESC_Firmware/can_testing`.

## Goal

Develop fresh STM32F405 CAN firmware with an architecture similar to the ESC-side structure used in MESC, so that proven high-bitrate CAN logic can be transferred back to ESC firmware with minimal refactoring.

## To run
Set compile time directive in MESC_Firmware
- `#define CAN_DIAG_COMPAT_V1 1`
- (it would be cool to have a can command set this state
- or a CLI command)

Open the teensy serial and type:
- `run`, `run 60` for a sixty second run
- `tx hz 250` to set the timing of IQREQ commands to 250 hz

default timing is now 500 hz. 

## Architecture Direction (Portability First)

Use ESC-like layering:
- `can_driver`: bxCAN/HAL init, filters, TX mailboxes, RX FIFO service, error-state access.
- `can_protocol`: frame IDs, sender/receiver/node addressing, payload pack/unpack, sequence counters.
- `can_scheduler`: periodic TX scheduling and timing ownership.
- `app_test_modes`: test orchestration (load profiles, burst modes, soak, fault-recovery checks).
- `diag_metrics`: counters/histograms/latency stats emitted to Teensy.

Design rule: protocol and scheduler interfaces should be written so files can be moved into ESC code with minimal API changes.

## Core Measurement Strategy

Teensy will receive sequenced telemetry/counter frames from STM32 and compute dropout and timing quality.

Primary outcomes:
- Determine stable operating bitrate and load envelope.
- Identify where failures start (dropouts, overruns, error-state escalation, latency tails).
- Produce a transport profile that is safe for balancing robot control.

## Metrics To Log Every Run

### Reliability and Ordering
- `seq_rx_total`
- `seq_missed_total`
- `seq_duplicate_total`
- `seq_out_of_order_total`
- `burst_miss_max`

### Timing Quality
- `gap_us_min`, `gap_us_p50`, `gap_us_p95`, `gap_us_p99`, `gap_us_max`
- `payload_age_us` (time since last valid message)
- end-to-end latency (when timestamped messages are enabled)

### Queue / Mailbox Health
- `tx_attempts`, `tx_ok`, `tx_fail`
- `tx_mailbox_full`
- `tx_enqueue_drop`
- `rx_fifo_overrun`
- `rx_queue_drop`

### Controller Error-State Health
- `can_tec`, `can_rec`
- `err_warn_count`
- `err_passive_count`
- `bus_off_count`
- protocol error class counters where available (ACK/bit/stuff/form/CRC)

### Runtime Correlation
- `loop_dt_us` stats and scheduler overruns on STM32
- any watchdog/reset reason indicators

## Phased Test Regime

## Phase 0: Electrical + Silent Bring-up
Duration: ~5 minutes
- Verify transceiver supply, standby pin behavior, common ground, termination.
- Start STM32 in listen-only then normal mode.

Pass:
- Valid frame detection.
- No immediate error-state escalation.

## What We Learned (Recent A/B + Soak)

### Summary
- The communication issue was not caused by CAN wire-level corruption.
- The command path from Teensy to STM32 was healthy during testing.
- The main reliability gain came from how the Teensy services receive traffic.

### Key Findings
- In dual-channel tests, CAN controller error indicators stayed clean (no persistent ACK/CRC/stuff/form/bit failures and no bus-off trend).
- STM32 command-receive sequence tracking showed no command-sequence loss during the validated runs.
- Configuring the ESC to transmit telemetry immediately (target <50 us) after the Teensy command ID significantly reduced dropouts and improved dual-channel reliability.
- With Teensy receive handled by polling in the main loop, message loss appeared in 30-second dual-channel tests.
- With Teensy receive handled by FIFO interrupt callbacks plus `events()` dispatch, the same test conditions showed zero lost telemetry sequence events.
- The Teensy RX path change is the primary improvement, but not the only requirement for stable performance.
- Stable runs also require correct command-to-bus mapping and node routing (node 11 on CAN2, node 12 on CAN1 in current wiring).
- Stable runs also require matching CAN bitrate on both devices (1 Mbps in current baseline tests).
- Stable runs also require hardware CAN filtering configured correctly on Teensy and STM32F405.
- Stable runs also depend on physical-layer health (powered transceivers, correct termination, and clean wiring/grounding).

### Practical Guidance
- Keep Teensy receive in interrupt/callback mode for this test framework.
- Keep node-to-bus routing aligned with physical wiring (node 11 on CAN2, node 12 on CAN1 in the current bench setup).
- Re-run the A/B check after major firmware or scheduler changes to confirm behavior remains stable.

## Variables Added and What They Proved

### 1) `CAN_RX_USE_ISR` (Teensy compile-time switch)
- Location: `teensy40/can_testing/src/main.h`
- Values:
  - `0` = receive by polling in `loop()`
  - `1` = receive by FIFO interrupt callback + `events()` dispatch
- What it proved:
  - This enabled a direct A/B comparison under the same wiring and test conditions.
  - Polling mode showed telemetry loss in dual-channel tests.
  - Interrupt/callback mode removed that loss in matched runs and 10-minute soak.

### 2) Callback-vs-main sequence counters (`CAN_INGRESS_SEQ` output)
- Location: `teensy40/can_testing/src/CAN_helper.cpp`, `teensy40/can_testing/src/test_can_transmit_mode.cpp`
- Added fields:
  - `left_cb_valid`, `left_cb_missed`, `left_cb_dup`, `left_cb_ooo`
  - `left_main_valid`, `left_main_missed`, `left_main_dup`, `left_main_ooo`
  - same for right side
- What it proved:
  - In polling mode, callback-level and main-level misses were both nonzero.
  - In interrupt/callback mode, both callback-level and main-level misses were zero.
  - This isolated the improvement to receive servicing behavior on Teensy.

### 3) STM32 command-sequence receive counters (`CAN_F405_IQREQ` output)
- Location: `MESC_Firmware/MESC_Interface/MESC/MESCinterface.c`, `teensy40/can_testing/src/CAN_helper.cpp`, `teensy40/can_testing/src/test_can_transmit_mode.cpp`
- Added fields:
  - `left_valid`, `left_missed`, `left_age_us`
  - `right_valid`, `right_missed`, `right_age_us`
- What it proved:
  - During validated runs, command-sequence misses on STM32 stayed at zero.
  - Therefore, command reception on STM32 was not the primary source of loss.

### 4) STM32 FIFO-overrun per-run deltas (`CAN_F405_OVR` output)
- Location: `MESC_Firmware/MESC_Interface/MESC/MESCinterface.c`, `teensy40/can_testing/src/test_can_transmit_mode.cpp`
- Added fields:
  - `left_fov0`, `left_fov1`, `left_fov_age_us`
  - `right_fov0`, `right_fov1`, `right_fov_age_us`
- What it proved:
  - In stable runs (including soak), these remained zero.
  - This aligned with zero observed sequence loss in the final validated configuration.

### 5) Node-to-bus transmit mapping constants
- Location: `teensy40/can_testing/src/main.h`
- Mapping used in validated setup:
  - node `11` -> CAN2
  - node `12` -> CAN1
- What it proved:
  - Keeping transmit routing aligned to physical wiring removed a source of avoidable timing and delivery instability.

### 6) Current command TX defaults
- `user_tx_period_us = 2000` (500 Hz) in `teensy40/can_testing/src/supervisor.h`
- Startup default in `teensy40/can_testing/src/main.cpp` also sets `user_tx_period_us = 2000`
- Balance mode uses `BALANCE_TX_PERIOD_US = 2000` (500 Hz) in `teensy40/can_testing/src/balance_TWR_mode.cpp`

## Impact on Robot Controller Architecture

For the intended system architecture (Teensy as the brain board, STM32F405 nodes as motor controllers), this testing outcome is significant:

- Dual-channel command and telemetry communication is now stable at 1 Mbps in the validated setup.
- A 10-minute soak test completed with zero observed telemetry sequence loss and zero command-sequence loss.
- No CAN controller error-state escalation or receive-overrun growth was observed in the stable runs.

## Practical implication:
- The communication layer is now suitable for closed-loop balancing and motion-control workloads where timing consistency matters.
- This lowers integration risk for using the Teensy as central supervisor/planner and F405 boards as motor-control endpoints.
- The same architecture remains portable to ESC-target firmware with less risk of reintroducing prior CAN reliability problems.

## CAN Comment Marker Legend

The source now includes inline markers to highlight reliability-focused edits:

- `CAN reliability improvement:` marks code paths that were changed to improve CAN robustness, timing, or observability.
- `CAN reliability improvement baseline:` marks default configuration values used in validated stable runs.

Primary files using these markers:

- `src/main.h`
- `src/main.cpp`
- `src/CAN_helper.h`
- `src/CAN_helper.cpp`
- `src/test_can_transmit_mode.cpp`
- `src/supervisor.h`
- `src/balance_TWR_mode.cpp`

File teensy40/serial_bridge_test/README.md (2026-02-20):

# System Summary: Teensy ⇄ ESP32 ⇄ Wi-Fi ⇄ Desktop

**An ESP32-WROOM-32 (Xtensa LX6) running Arduino firmware acts as a
Wi-Fi TCP bridge between Teensy 4.0 Serial1 (GPIO16/17 via UART2) and a
desktop client, enabling reliable post-run binary data transfer over the
home network using mDNS discovery (`twr-repeater.local:9000`).**

## ESP32 hardware & architecture

**Board:** WEMOS D1 mini ESP32--class (module: **ESP32-WROOM-32**)\
**Chip:** **ESP32-D0WD-V3**\
**CPU:** Dual-core **Xtensa LX6 @ 240 MHz**\
**RAM:** 520 KB internal\
**Flash:** external (typically 4 MB)\
**USB:** via CH340 → **UART0 only** (not native USB)

Framework: **Arduino (PlatformIO compatible)**

------------------------------------------------------------------------

## UART usage on the ESP32

### Reserved

-   **UART0 → `Serial` → USB**
    -   GPIO1 = TX0\
    -   GPIO3 = RX0\
        Used for:
    -   flashing
    -   debug prints\
        **Not connected to the Teensy**

### Teensy link

Using **UART2** (remappable and safe):

  Function   ESP32 GPIO   Connects to Teensy
  ---------- ------------ ------------------------
  ESP32 RX   **GPIO16**   Teensy **TX1 (pin 1)**
  ESP32 TX   **GPIO17**   Teensy **RX1 (pin 0)**
  GND        GND          GND

Baud rate: **115200**

------------------------------------------------------------------------

## LED

**GPIO2** - 250 ms heartbeat when idle - Solid/flicker when UART data is
being received

------------------------------------------------------------------------

# Wi-Fi configuration

ESP32 runs in **STA mode** and connects to:

-   **SSID:** `Monty's Love Factory`
-   **Password:** `HotMonkeyMonty`

Network discovery via:

-   **mDNS hostname:**\
    `twr-repeater.local`

TCP server:

-   **Port:** `9000`

------------------------------------------------------------------------

# Data flow architecture

## Physical chain

Teensy 4.0\
Serial1 (115200)\
│\
▼\
ESP32 UART2 (GPIO16/17)\
│\
▼\
ESP32 Wi-Fi (STA mode)\
│\
▼\
Home network\
│\
▼\
Desktop Python client (TCP)

------------------------------------------------------------------------

## Logical behavior

### ESP32 role

The ESP32 is a **transparent binary bridge**.

It:

1.  Connects to house Wi-Fi\
2.  Advertises via mDNS (`twr-repeater.local`)\
3.  Opens TCP server on port 9000\
4.  Forwards bytes

#### Teensy → Desktop

UART2 RX → TCP socket

#### Desktop → Teensy

TCP socket → UART2 TX

No packet interpretation. No protocol logic. Pure byte pipe.

------------------------------------------------------------------------

## Current tested behavior

### Verified working

-   Teensy test packets transmitted on Serial1\
-   ESP32 receives them → confirmed by increasing `UART_RX`\
-   Desktop connects via `twr-repeater.local:9000`\
-   Desktop receives correct number of bytes over TCP\
-   End-to-end chain validated

------------------------------------------------------------------------

# Current operating mode

This is a **post-run bulk transfer system**:

-   Teensy logs data locally during the robot run\
-   After the run it sends a single stream over Serial1\
-   ESP32 forwards that stream over Wi-Fi to the desktop

So this is **not a real-time telemetry link** --- it is a **reliable
dump channel**.

------------------------------------------------------------------------

# Debug instrumentation currently in firmware

ESP32 prints once per second:

    [STATS] up=XXs
    WiFi=OK/DOWN
    TCP=CONNECTED/none
    UART_RX=bytes
    UART_TX=bytes
    TCP_RX=bytes
    TCP_TX=bytes

This allows immediate diagnosis of:

-   UART wiring\
-   Wi-Fi status\
-   Desktop connection\
-   Direction of data flow

------------------------------------------------------------------------

# Desktop side

Python connects using hostname:

``` python
socket.create_connection(("twr-repeater.local", 9000))
```

No IP hard-coding required.

Current test: - Receive raw bytes\
- Count total received

------------------------------------------------------------------------

# What this system is (conceptually)

A **binary-safe wireless serial tunnel** between:

-   a real-time controller (**Teensy 4.0**)\
-   a high-level logging/analysis computer

with:

-   no timing impact on the control loop\
-   no USB tether\
-   reliable transport via TCP

------------------------------------------------------------------------

# What has NOT been added yet (by design)

These are future features, not missing pieces:

-   Command protocol (e.g., "start dump" trigger)\
-   Length-prefixed transfer\
-   CRC / integrity check\
-   Ring buffer for late TCP connects\
-   AP fallback mode

The transport layer itself is complete and validated.

------------------------------------------------------------------------

# Minimal wiring reference

### Teensy 4.0 ⇄ ESP32

Teensy pin 1 (TX1) → ESP32 GPIO16\
Teensy pin 0 (RX1) ← ESP32 GPIO17\
GND ↔ GND

USB remains connected only to ESP32 for flashing/debug.

------------------------------------------------------------------------
# ESP CODE
```c
#include <WiFi.h>
#include <ESPmDNS.h>

// ======== User config ========
static const char* WIFI_SSID = "Love Factory";
static const char* WIFI_PASS = "ILoveLyra";

static const char* MDNS_NAME = "twr-repeater";   // => twr-repeater.local
static const uint16_t TCP_PORT = 9000;

// UART to Teensy (ESP32 side). Use UART2 by default.
static const int UART_NUM = 2;
static const int UART_RX_PIN = 16;               // ESP32 RX  (connect to Teensy TX1)
static const int UART_TX_PIN = 17;               // ESP32 TX  (connect to Teensy RX1)
static const uint32_t UART_BAUD = 115200;

// Debug serial (USB) baud
static const uint32_t DEBUG_BAUD = 115200;

// LED / heartbeat
static const int LED_PIN = 2;                    // GPIO2 is common onboard LED
static const uint32_t HEARTBEAT_MS = 250;

// LED RX-activity timing (when receiving data from Teensy over UART)
static const uint32_t RX_LED_HOLD_MS = 40;       // LED stays ON this long after last RX byte

// Buffers
static const size_t BUF_SZ = 1024;
// ============================

WiFiServer server(TCP_PORT);
WiFiClient client;
HardwareSerial TeensyUart(UART_NUM);

uint32_t lastBlinkMs = 0;
bool ledState = false;

// If millis() < rxLedUntilMs, force LED ON to indicate UART RX activity
uint32_t rxLedUntilMs = 0;

// ---- Debug counters ----
volatile uint32_t uartRxBytes = 0;
volatile uint32_t uartTxBytes = 0;
volatile uint32_t tcpRxBytes  = 0;
volatile uint32_t tcpTxBytes  = 0;

uint32_t lastStatsMs = 0;
uint32_t bootMs = 0;
// ------------------------

static void wifiConnect()
{
  WiFi.mode(WIFI_STA);
  WiFi.setSleep(false);
  WiFi.begin(WIFI_SSID, WIFI_PASS);

  Serial.print("WiFi connecting to: ");
  Serial.println(WIFI_SSID);

  uint32_t start = millis();
  while (WiFi.status() != WL_CONNECTED) {
    delay(200);
    Serial.print(".");
    if (millis() - start > 15000) {
      Serial.println("\nWiFi connect timeout; retrying...");
      WiFi.disconnect(true);
      delay(200);
      WiFi.begin(WIFI_SSID, WIFI_PASS);
      start = millis();
    }
  }

  Serial.println("\nWiFi connected.");
  Serial.print("IP: ");
  Serial.println(WiFi.localIP());
}

static void mdnsStart()
{
  MDNS.end();

  if (!MDNS.begin(MDNS_NAME)) {
    Serial.println("mDNS start failed (continuing without it).");
    return;
  }
  MDNS.addService("twr", "tcp", TCP_PORT);

  Serial.print("mDNS: ");
  Serial.print(MDNS_NAME);
  Serial.println(".local");
}

static void ledTick()
{
  uint32_t now = millis();

  if (now < rxLedUntilMs) {
    digitalWrite(LED_PIN, HIGH);
    return;
  }

  if (now - lastBlinkMs >= HEARTBEAT_MS) {
    lastBlinkMs = now;
    ledState = !ledState;
    digitalWrite(LED_PIN, ledState ? HIGH : LOW);
  }
}

static void acceptClientIfNeeded()
{
  if (client && client.connected()) return;

  if (client) {
    client.stop();
  }

  WiFiClient newClient = server.available();
  if (newClient) {
    client = newClient;
    client.setNoDelay(true);

    Serial.print("TCP client connected from: ");
    Serial.println(client.remoteIP());
  }
}

static void pumpTcpToUart()
{
  if (!client || !client.connected()) return;

  uint8_t buf[BUF_SZ];
  int avail = client.available();
  if (avail <= 0) return;

  int toRead = (avail > (int)BUF_SZ) ? (int)BUF_SZ : avail;
  int n = client.read(buf, toRead);
  if (n > 0) {
    tcpRxBytes += (uint32_t)n;
    TeensyUart.write(buf, n);
    uartTxBytes += (uint32_t)n;

    // Debug: only print occasionally to avoid spam
    // Serial.printf("TCP->UART %d bytes\n", n);
  }
}

static void pumpUartToTcp()
{
  // IMPORTANT: We still want to confirm we are receiving UART data even if no TCP client.
  uint8_t buf[BUF_SZ];
  int avail = TeensyUart.available();
  if (avail <= 0) return;

  int toRead = (avail > (int)BUF_SZ) ? (int)BUF_SZ : avail;

  TeensyUart.setTimeout(2);
  int n = TeensyUart.readBytes(buf, toRead);

  if (n > 0) {
    uartRxBytes += (uint32_t)n;

    // Trigger LED RX activity indicator
    rxLedUntilMs = millis() + RX_LED_HOLD_MS;

    // Debug: show first few bytes of the first packet after boot
    static bool showedSample = false;
    if (!showedSample) {
      showedSample = true;
      Serial.print("UART RX sample (first 16 bytes): ");
      int m = (n < 16) ? n : 16;
      for (int i = 0; i < m; i++) {
        if (buf[i] < 16) Serial.print("0");
        Serial.print(buf[i], HEX);
        Serial.print(" ");
      }
      Serial.println();
    }

    // If TCP client exists, forward; otherwise just drop (but counters prove receipt)
    if (client && client.connected()) {
      client.write(buf, n);
      tcpTxBytes += (uint32_t)n;
    }
  }
}

static void statsTick()
{
  uint32_t now = millis();
  if (now - lastStatsMs < 1000) return;
  lastStatsMs = now;

  Serial.print("[STATS] up=");
  Serial.print((now - bootMs) / 1000);
  Serial.print("s  WiFi=");
  Serial.print((WiFi.status() == WL_CONNECTED) ? "OK" : "DOWN");
  Serial.print("  TCP=");
  Serial.print((client && client.connected()) ? "CONNECTED" : "none");
  Serial.print("  UART_RX=");
  Serial.print(uartRxBytes);
  Serial.print("B  UART_TX=");
  Serial.print(uartTxBytes);
  Serial.print("B  TCP_RX=");
  Serial.print(tcpRxBytes);
  Serial.print("B  TCP_TX=");
  Serial.print(tcpTxBytes);
  Serial.println("B");
}

void setup()
{
  pinMode(LED_PIN, OUTPUT);
  digitalWrite(LED_PIN, LOW);

  Serial.begin(DEBUG_BAUD);
  delay(300);

  bootMs = millis();
  Serial.println();
  Serial.println("=== ESP32 TWR repeater boot ===");
  Serial.printf("Build: %s %s\n", __DATE__, __TIME__);
  Serial.printf("UART2 pins: RX=%d TX=%d baud=%lu\n", UART_RX_PIN, UART_TX_PIN, (unsigned long)UART_BAUD);
  Serial.printf("WiFi SSID: %s\n", WIFI_SSID);
  Serial.printf("TCP port: %u  mDNS: %s.local\n", TCP_PORT, MDNS_NAME);

  TeensyUart.begin(UART_BAUD, SERIAL_8N1, UART_RX_PIN, UART_TX_PIN);
  TeensyUart.setRxBufferSize(8 * 1024);

  Serial.println("TeensyUart started.");

  wifiConnect();
  mdnsStart();

  server.begin();
  Serial.print("TCP server listening on port ");
  Serial.println(TCP_PORT);
}

void loop()
{
  ledTick();
  statsTick();

  if (WiFi.status() != WL_CONNECTED) {
    Serial.println("WiFi disconnected; reconnecting...");
    wifiConnect();
    mdnsStart();
    server.begin();
  }

  acceptClientIfNeeded();

  pumpTcpToUart();
  pumpUartToTcp();

  delay(1);
}

```
-------------------------------------------------
# TEENSY CODE
```c
#include <Arduino.h>

#define TEST_INTERVAL_MS 1000

// A simple binary test packet
struct TestPacket {
  uint32_t counter;
  uint32_t millisStamp;
  uint8_t  payload[16];
};

uint32_t lastSend = 0;
uint32_t txCounter = 0;

void sendTestPacket()
{
  TestPacket pkt;

  pkt.counter = txCounter++;
  pkt.millisStamp = millis();

  for (int i = 0; i < 16; i++) {
    pkt.payload[i] = i + pkt.counter;
  }

  Serial1.write((uint8_t*)&pkt, sizeof(pkt));

  Serial.print("Sent packet #");
  Serial.print(pkt.counter);
  Serial.print("  size=");
  Serial.println(sizeof(pkt));
}

void setup()
{
  Serial.begin(115200);
  while (!Serial && millis() < 4000) {}

  Serial.println("\nTeensy Serial1 <-> ESP32 link test");

  Serial1.begin(115200);
}

void loop()
{
  // Send a packet once per second
  if (millis() - lastSend >= TEST_INTERVAL_MS) {
    lastSend = millis();
    sendTestPacket();
  }

  // Check for data coming back from ESP32
  while (Serial1.available()) {
    uint8_t b = Serial1.read();

    Serial.print("RX byte from ESP32: 0x");
    if (b < 16) Serial.print("0");
    Serial.println(b, HEX);
  }
}

```
-------------------------------------------------
# PYTHON CODE
```c
#!/usr/bin/env python3

import socket, time
s = socket.create_connection(("twr-repeater.local", 9000), timeout=5)
s.settimeout(1.0)
t0 = time.time()
total = 0
while time.time() - t0 < 5:
    try:
        d = s.recv(4096)
        if not d: break
        total += len(d)
    except socket.timeout:
        pass
print("received", total, "bytes")
s.close()

```

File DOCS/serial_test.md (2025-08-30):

# Serial Transmission Performance Plots

## 1. Inter-arrival Time Plots ⏱️
- **What:** time between received packets vs time  
- **Why:** shows jitter and gaps. Ideally flat (e.g. 10 ms if 100 Hz)  
- **Variants:**  
  - Histogram of inter-arrival times → see spread  
  - CDF plot → see “99% of packets arrive within X ms”

## 2. Throughput vs Time 📊
- **What:** bytes per second (or packets per second), computed in rolling windows  
- **Why:** confirms you’re sustaining expected rates (e.g. 100 packets/s)  
- **Variant:** per-message ID breakdown (if multiple IDs are logged)

## 3. Sequence Number Gaps 🚧
- **What:** received `seq` vs expected sequence; plot missing/gap events  
- **Why:** any non-zero gaps = packet loss  
- **Display:** raster of loss events or cumulative loss counter

## 4. Queue Depth / Buffer Occupancy 📉
- **What:** TX and RX queue depth over time  
- **Why:** visualize back-pressure; rising depth means consumer can’t keep up  
- **Add:** plot high-water marks reset each interval

## 5. Latency (if you stamp) 📡
- **What:** plot `t_rx – t_tx` per packet (end-to-end delay)  
- **Why:** shows true transmission + buffering delay  
- **Variants:**  
  - Histogram (distribution of latency)  
  - Jitter plot (std dev or min/max bands)

## 6. Drop/Error Events ❌
- **What:** time-series of `drops` counters or CRC failures  
- **Why:** pinpoints bursts that cause overruns or framing errors

## 7. Aggregate Stats Panel 📋
- **Mean / Std of inter-arrival (ms)**  
- **% loss**  
- **Max observed queue depth**  
- **CPU % (optional)**

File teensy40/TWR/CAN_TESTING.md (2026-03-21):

# CAN Testing Notes

## User-Reported Issues and Investigation History

1. We are debugging intermittent CAN telemetry loss/jitter between Teensy 4.0 receiver and STM32F405 ESC nodes (ID 11 and 12), mainly POS/VEL at about 500 Hz per node.
2. Early "missed" metrics were partly misleading because sequence checks were done in the 1 kHz control loop instead of per-CAN-frame receive path.
3. We added per-frame sequence accounting in Teensy CAN RX path (`left_seq_*`, `right_seq_*`, burst counters). This is now the trusted drop metric.
4. Teensy-side TX queue/fail diagnostics on ESC side were mostly clean (`enqueue_fail=0`, `hal_tx_fail=0`), so many losses were not from obvious HAL enqueue failures.
5. Enabling torque command traffic increased mailbox pressure and worsened telemetry fidelity; disabling torque improved results.
6. Serial1 activity on Teensy clearly hurt CAN receive quality. Disabling Serial1 reduced misses and max gaps substantially.
7. Physical layer/cabling has a strong effect. Twisted/shielded CAN pair improved average runs, but intermittent burst failures still appear.
8. Asymmetry between nodes was observed repeatedly (sometimes node 12 worse, other times node 11), suggesting mixed causes (electrical + timing/scheduling), not one single deterministic firmware bug.
9. Some tests showed severe periodic stalls/bursts (counts dropping to about 1200 to 1900 over windows where about 2400 expected, and very large max gaps). This happened even with motors disconnected in some cases.
10. Startup/warmup polluted max-gap metrics initially; we added warmup gating and per-button-run reset logic to reduce false interpretation.
11. We also built a clean no-RTOS STM32 CAN smoke-test project (PB8 = CAN1_RX AF9, PB9 = CAN1_TX AF9) to isolate ESC-stack effects from full MESC/RTOS behavior.
12. Current status: still intermittent reliability issues; likely contributors are electrical integrity plus occasional scheduling/servicing stalls under certain runtime conditions. No single conclusive root cause yet.

## Current Code Concerns (This `can_testing` Branch)

### Core concerns in `CAN_helper` + `main`

1. Trusted per-frame sequence-drop metrics are not present in this branch's `CAN_helper` stats structure; only timing-gap estimates (`est_missed`) are currently tracked.
2. Software RX ring buffer is small (`CAN_BUF_SIZE=32`) and overflows are not emitted in diagnostics, which can hide drops during brief service stalls.
3. Serial1 telemetry output is active in test mode and can perturb CAN RX performance, which risks contaminating transport test results.
4. Test start paths currently do not reset CAN RX stats/overflow counters, so prior-run and startup transients can pollute measurements.
5. RX parsing does not validate frame shape (`extended` flag and payload length) before decoding floats.

### Concerns in `test_can_transmit_mode`

1. ESC-alive guard checks only the left ESC; right ESC loss can be missed.
2. Torque TX is sent every 1 kHz control tick (two commands per tick), which increases CAN load and may worsen telemetry loss during diagnostics.
3. The mode currently reports timing/new-sample telemetry but does not directly report trusted per-frame sequence continuity counters.
4. `SUP_MODE_BALANCE_TWR` is also routed to `test_can_transmit_mode`, which can cause unintended behavior if balance mode is expected to be separate.
5. `dt_pos_us` telemetry averages left/right timing even when only one side is fresh, which can mask one-sided stalls.
6. The startup log message says "Balance mode started" even when this test transmit mode is running.

## Practical Test Guidance (Short)

1. For pure transport characterization, keep torque TX and Serial1 diagnostics independently gateable at compile time.
2. Always report per-frame sequence continuity counters and software overflow counters in summaries.
3. Reset all RX/drop metrics at run start (after warmup gate if used) to keep windows comparable.

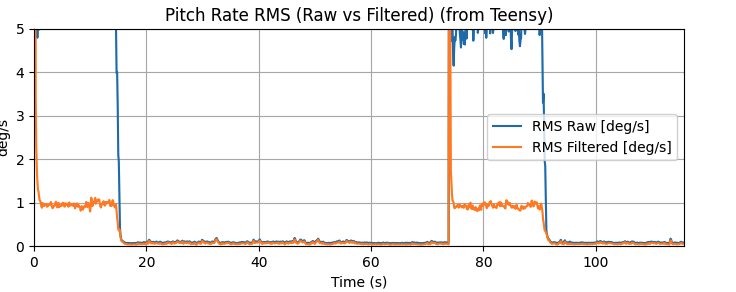
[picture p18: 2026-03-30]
teensy40/can_testing/docs/imu_rms_plot_2026-03-28.png

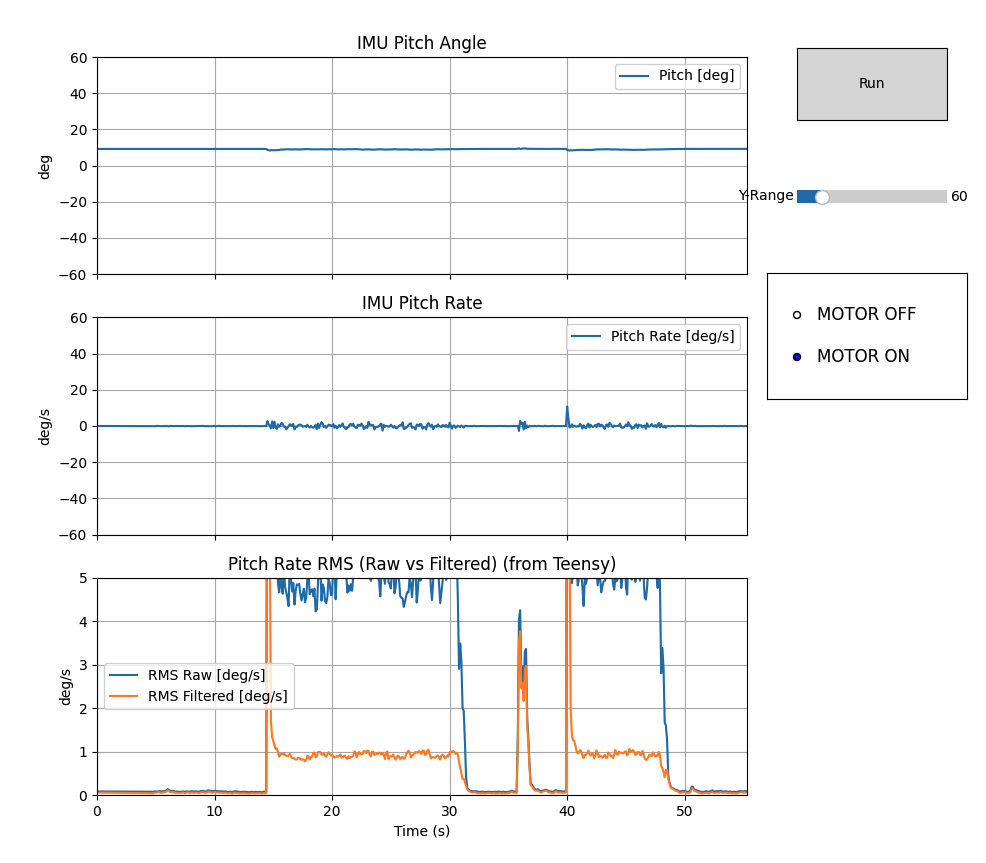
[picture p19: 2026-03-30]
teensy40/can_testing/vibe_testing1.png

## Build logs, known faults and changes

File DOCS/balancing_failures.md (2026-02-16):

# Failure Modes & Watchdogs Checklist

Common issues that can break balancing in the brain board project, along with what to watch for and how to mitigate them.

---

## Model–Reality Gaps
- **Cause:** Wrong mass, inertia, COM height, motor constants, friction, or linearization errors.
- **Watch:** Compare predicted vs measured response, recovery time, deviations from simulation.
- **Mitigation:** Log commanded vs actual response, refine A/B matrices via system identification.

---

## IMU Problems
- **Cause:** Gyro bias drift, accelerometer noise
- **Watch:** Sudden jumps in angle/velocity, gyro bias while stationary, encoder inconsistency.
- **Mitigation:** Log vibration, [calibrate IMU](../teensy40/vibration_testing/README.md), add filtering (complementary/Kalman)

---

## ESC Problems
- **Cause:** Bad current limits, encoder measurement, motor settings.
- **Watch:** Motors behave poorly, assymetric motor behavior
- **Mitigation:** Log movement, test CAN commands, set out-of-range values, check torques, calibrate encoder offsets

---

## Actuator Saturation
- **Cause:** Motors can’t provide commanded torque at high tilt or disturbance.
- **Watch:** Torque command clipping at ±max, battery sag under load.
- **Mitigation:** Log % time saturated, trigger warnings, penalize torque in LQR (larger R), add anti-windup logic.

---

## Timing Jitter & Delays
- **Cause:** Control loop not running exactly at 500 Hz due to blocking I/O or CAN bursts.
- **Watch:** Control loop dt distribution, flag dt > 3–4 ms.
- **Mitigation:** Keep control loop deterministic, throttle telemetry, measure jitter with GPIO/DWT, abort if timing drift exceeds threshold.

---

## Communication Latency / Loss
- **Cause:** CAN congestion, delayed encoder updates, ESP32 UART backpressure.
- **Watch:** Gaps in encoder/velocity updates, node alive status toggling.
- **Mitigation:** Add timeout counters, log packet inter-arrival times, fail safe to idle if CAN stalls.

---

## Startup Conditions
- **Cause:** Robot starts too tilted (>15°) for linearization to hold.
- **Watch:** Initial tilt angle when enabling balance mode.
- **Mitigation:** Require tilt < 5° before enabling control, otherwise refuse to engage.

---

## Asymmetry & Cross-Coupling
- **Cause:** Left/right motors behave differently, leading to yaw drift.
- **Watch:** Persistent yaw when balancing in place.
- **Mitigation:** Calibrate wheel gains, extend state model to include yaw if necessary.

---

## Physical Robot Issues
- **Frame Flexibility / Looseness**  
  - **Cause:** Weak materials, loose bolts, frame compliance.  
  - **Watch:** Buzzing or oscillation not predicted by model.  
  - **Mitigation:** Rigid frame, moongel, thread-lock, stiffening braces.

- **Wheel Slippage**  
  - **Cause:** Low friction tires/surfaces.  
  - **Watch:** Encoder motion without tilt correction.  
  - **Mitigation:** High-friction tires, textured surfaces.

- **Wheel Backlash / Play**  
  - **Cause:** Loose coupling or gears.  
  - **Watch:** Delay between torque and wheel motion.  
  - **Mitigation:** Eliminate play, use direct drive.

- **Asymmetric Hardware**  
  - **Cause:** Unequal wheel/motor behavior.  
  - **Watch:** Constant yaw drift.  
  - **Mitigation:** Match components, calibrate offsets.

- **Center of Mass Shifts**  
  - **Cause:** Payload or battery off-center.  
  - **Watch:** Falls faster than predicted.  
  - **Mitigation:** Keep COM low/centered, secure loads.

- **Structural Resonances**  
  - **Cause:** Flexible members vibrating.  
  - **Watch:** High-frequency IMU oscillations.  
  - **Mitigation:** Stiffen frame, add damping. See [this discussion](../teensy40/vibration_testing/README.md)

- **Loose Encoders / Misalignment**  
  - **Cause:** Poor encoder mount.  
  - **Watch:** Phantom encoder ticks while stationary.  
  - **Mitigation:** Rigid mounting, use Z-index pulse.

- **Electrical / Power Issues**  
  - **Cause:** Loose connectors, voltage sag, brownouts.  
  - **Watch:** Sudden resets, dropouts.  
  - **Mitigation:** Secure wiring, proper gauge, capacitors.

---

# Robustness Strategy
- **Measure:** Collect metrics on dt, saturation, packet loss, sensor bias.
- **Log:** Histograms and distributions to spot drift and load trends.
- **React:** Use thresholds, timeouts, alarms, and safe torque cutoffs.

**Principle:** Anticipate → Instrument → React.

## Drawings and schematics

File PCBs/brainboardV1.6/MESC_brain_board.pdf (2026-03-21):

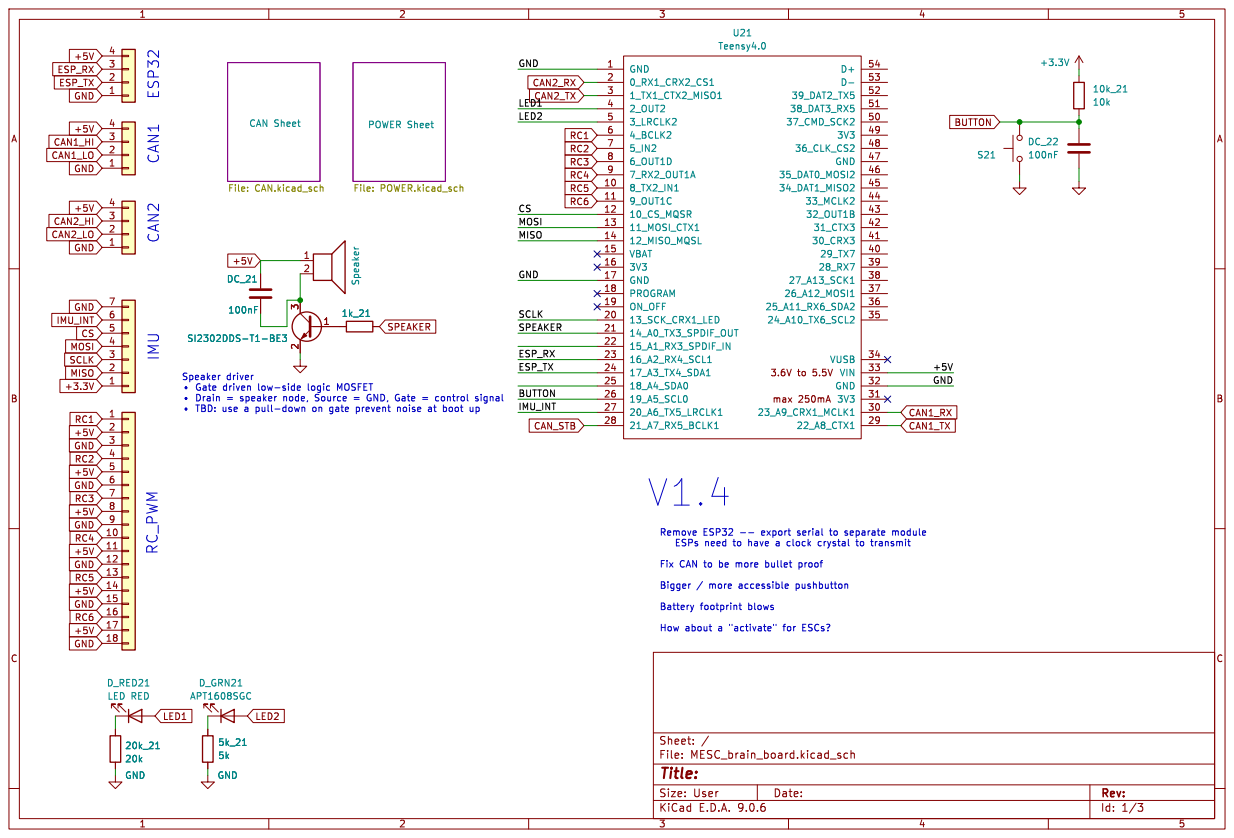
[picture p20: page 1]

POWER Sheet File: POWER.kicad_sch CAN Sheet File: CAN.kicad_sch

Id: 1/3 Title: File: MESC_brain_board.kicad_sch Sheet: /

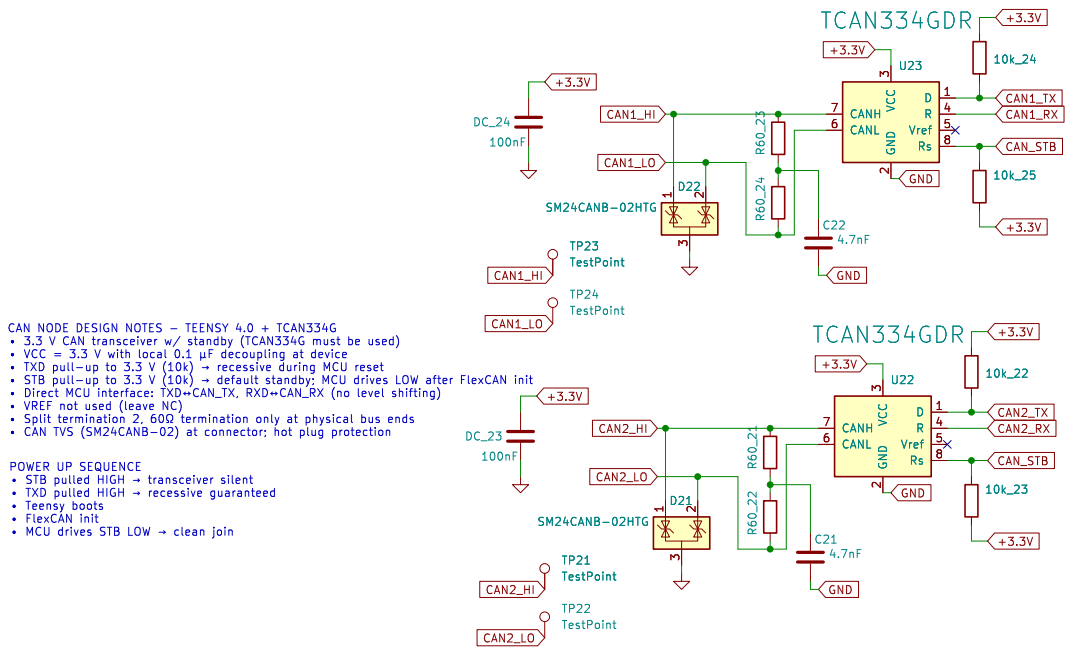
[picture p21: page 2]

þÿ "Teensy boots þÿ "FlexCAN init þÿ "MCU drives STB LOW þÿ!’clean join CAN NODE DESIGN NOTES - TEENSY 4.0 + TCAN334G

þÿ "VREF not used (leave NC)

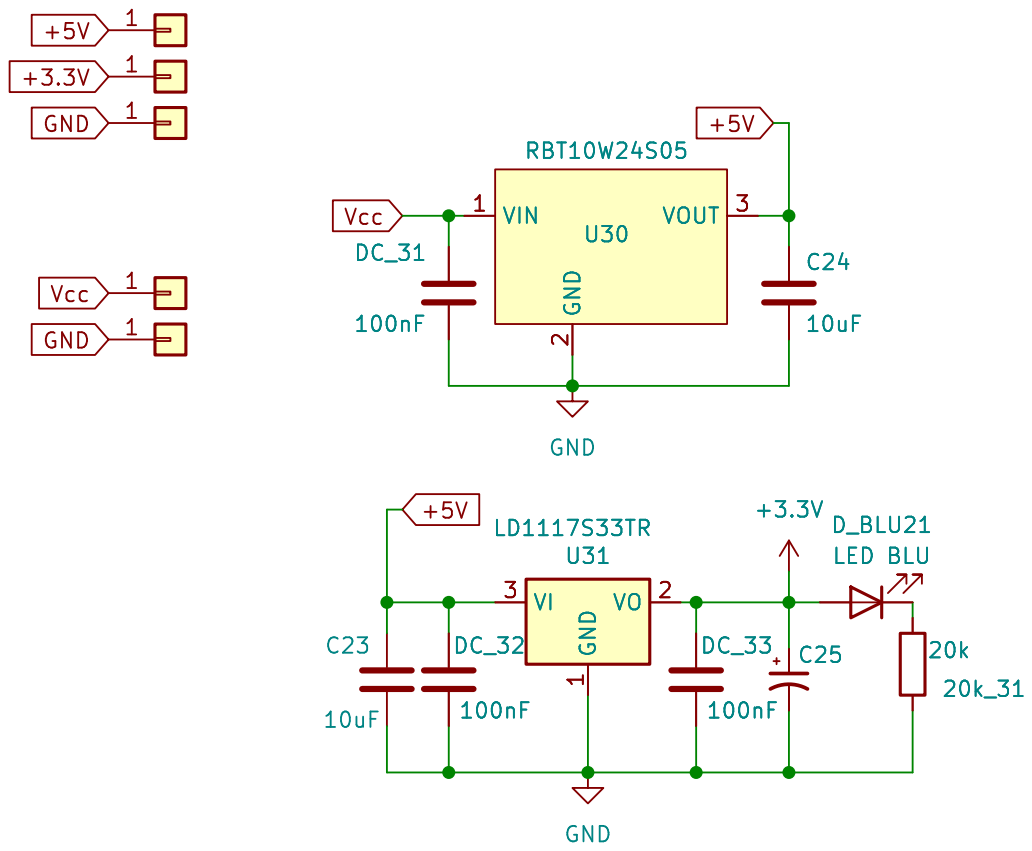
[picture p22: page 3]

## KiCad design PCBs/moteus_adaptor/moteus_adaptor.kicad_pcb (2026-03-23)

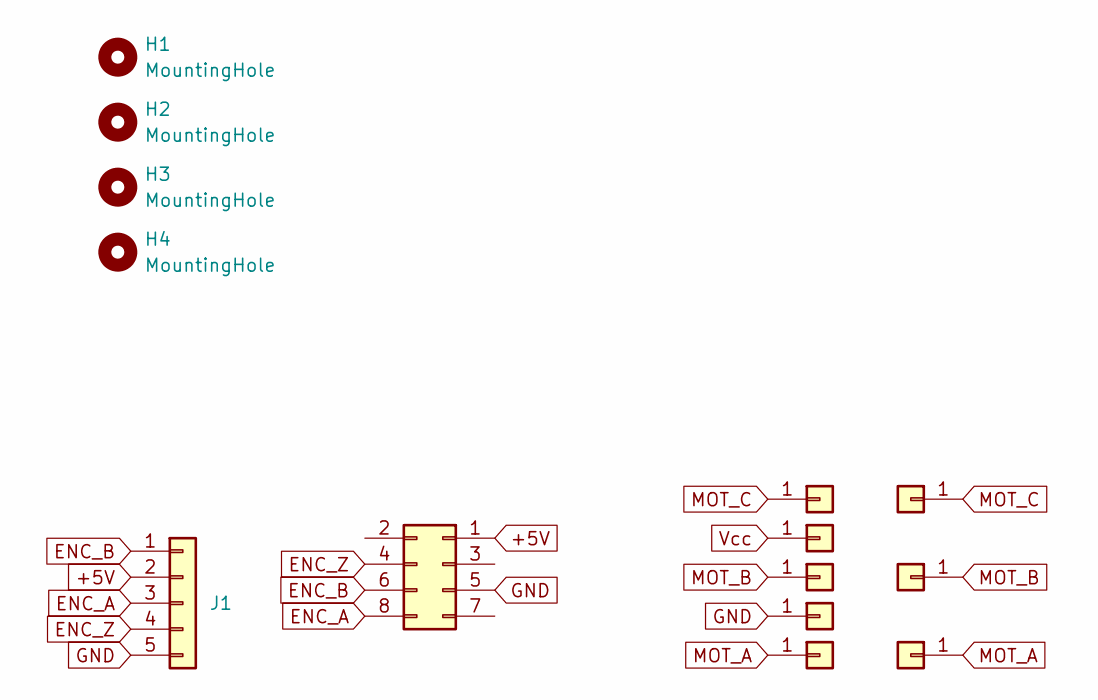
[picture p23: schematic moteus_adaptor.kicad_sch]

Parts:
H1, H2, H3, H4: MountingHole; MountingHole_2.5mm
J1: Conn_01x05; PinHeader_1x05_P2.54mm_Vertical
J2: Conn_02x04_Odd_Even; PinSocket_2x04_P1.27mm_Vertical
J3, J4, J5, J6, J7: Conn_01x01; my_Pin_D2.0mm
J8, J10, J12: Conn_01x01; my_Pin_D2.6mm

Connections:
+5V: J1.2, J2.1
ENC_A: J1.3, J2.8
ENC_B: J1.1, J2.6
ENC_Z: J1.4, J2.4
GND: J1.5, J2.5, J5.1
MOT_A: J6.1, J12.1
MOT_B: J4.1, J10.1
MOT_C: J7.1, J8.1
Vcc: J3.1

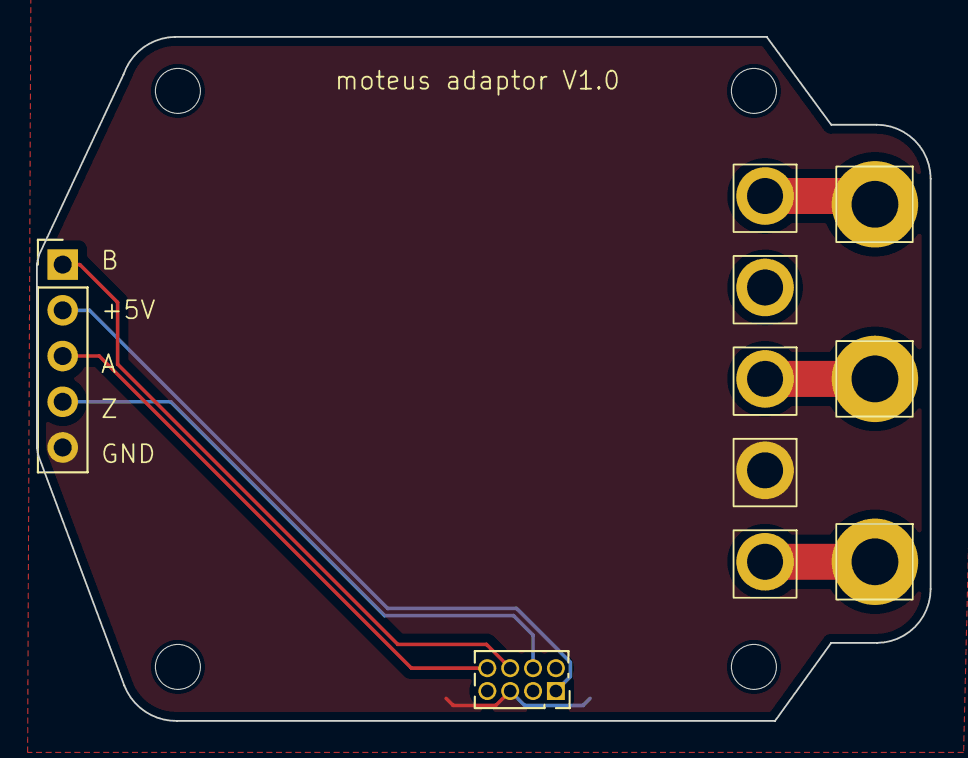
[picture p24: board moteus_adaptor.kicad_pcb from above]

Board: 2 copper layers, 49.7 x 38.0 mm, 14 parts (0 on the bottom side), 8 nets.

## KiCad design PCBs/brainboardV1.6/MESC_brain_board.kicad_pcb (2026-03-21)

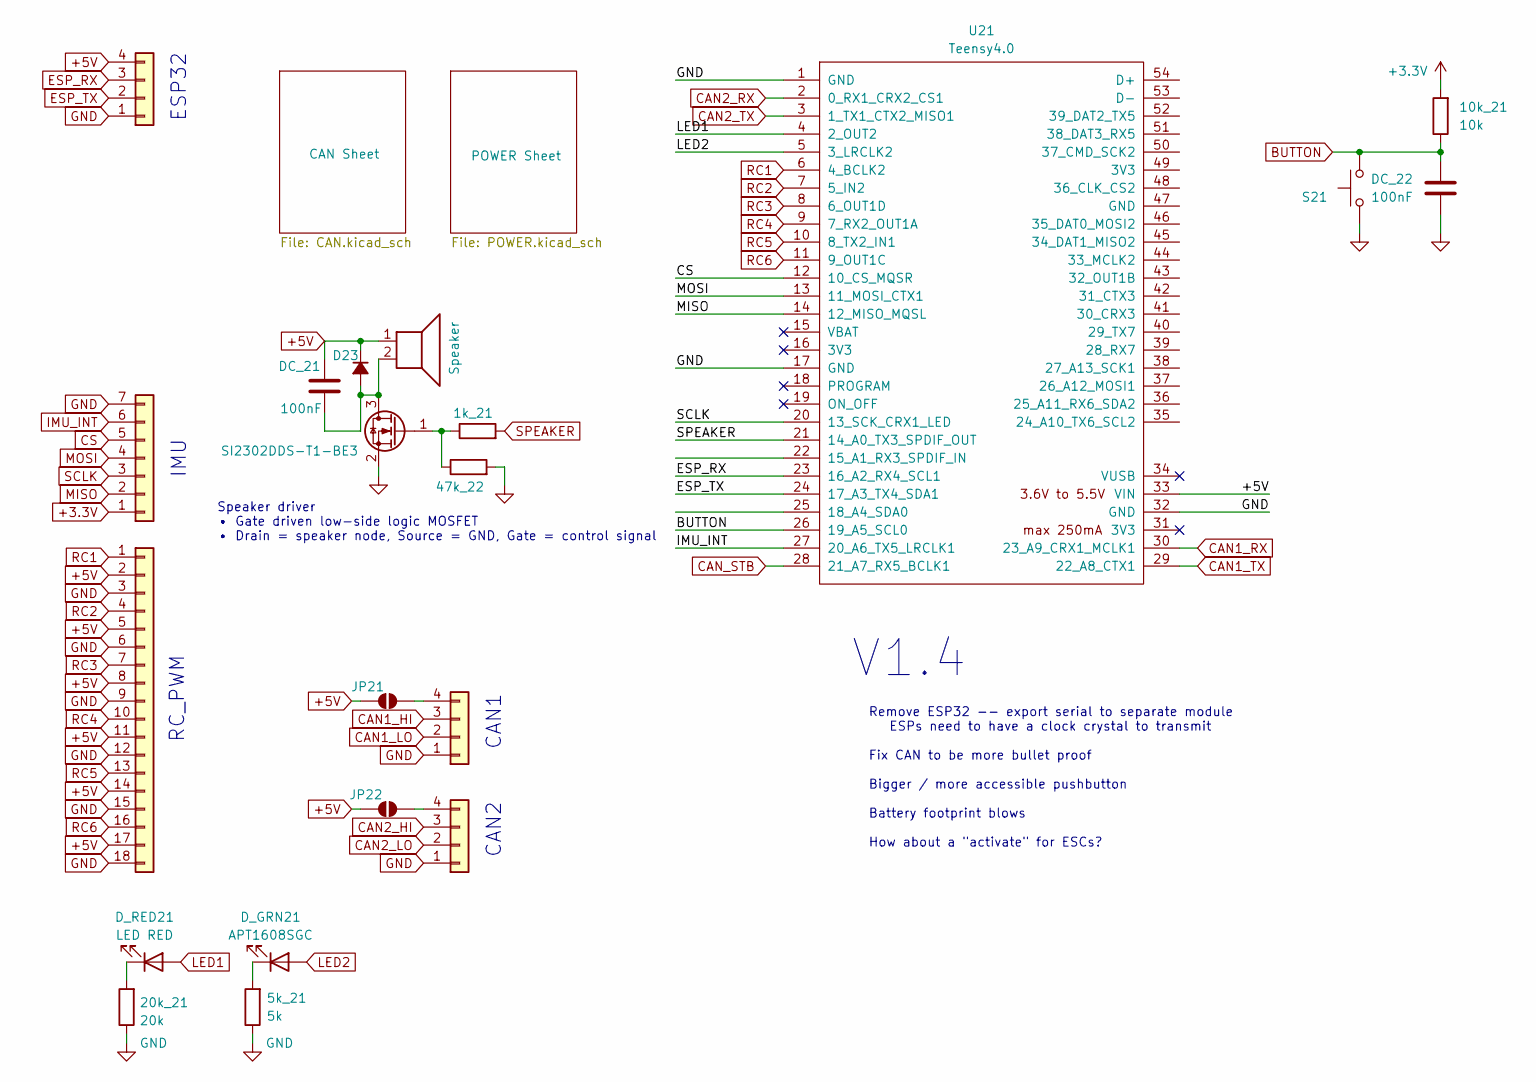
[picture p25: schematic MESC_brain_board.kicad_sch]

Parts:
1k_21, 47k_22: 10k; R_0603_1608Metric
5k_21: 5k; R_0603_1608Metric; LCSC C4184
10k_21: 10k; R_0603_1608Metric; LCSC C25804
20k_21: 20k; R_0603_1608Metric; LCSC C4184
CAN1, CAN2: Conn_01x04; JST_PH_B4B-PH-K_1x04_P2.00mm_Vertical
D23: D_Small_Filled; D_SMA
DC_21: 100nF; C_0603_1608Metric
DC_22: 100nF; C_0603_1608Metric; LCSC C14663
D_GRN21: APT1608SGC; LED_0603_1608Metric; LCSC APT1608SGC
D_RED21: LED RED; LED_0603_1608Metric; LCSC APT1608SURCK
ESP1: Conn_01x04; JST_PH_B4B-PH-K_1x04_P2.00mm_Vertical
IMU1: Conn_01x07; JST_PH_B7B-PH-K_1x07_P2.00mm_Vertical
J2: Conn_01x18; my_PinSocket_3x07_P2.54mm_Vertical
JP21, JP22: SolderJumper_2_Open; SolderJumper-2_P1.3mm_Open_RoundedPad1.0x1.5mm
LS21: Speaker; SPKR_CDS-13138-SMT-TR
Q21: SI2302DDS-T1-BE3; SOT-23
S21: TL1015AF160QG; SW_Push_SPST_NO_Alps_SKRK
U21: Teensy4.0; Teensy40

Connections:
+3.3V: 10k_21.2, IMU1.1; also elsewhere on the board
+5V: D23.1 (K), DC_21.1, ESP1.4, J2.2, J2.5, J2.8, J2.11, J2.14, J2.17, JP21.1 (A), JP22.1 (A), LS21.1, U21.33 (VIN); also elsewhere on the board
BUTTON: 10k_21.1, DC_22.2, S21.2, U21.26 (19_A5_SCL0)
CAN1_HI: CAN1.3; also elsewhere on the board
CAN1_LO: CAN1.2; also elsewhere on the board
CAN1_RX: U21.30 (23_A9_CRX1_MCLK1); also elsewhere on the board
CAN1_TX: U21.29 (22_A8_CTX1); also elsewhere on the board
CAN2_HI: CAN2.3; also elsewhere on the board
CAN2_LO: CAN2.2; also elsewhere on the board
CAN2_RX: U21.2 (0_RX1_CRX2_CS1); also elsewhere on the board
CAN2_TX: U21.3 (1_TX1_CTX2_MISO1); also elsewhere on the board
CAN_STB: U21.28 (21_A7_RX5_BCLK1); also elsewhere on the board
CS: IMU1.5, U21.12 (10_CS_MQSR)
ESP_RX: ESP1.3, U21.23 (16_A2_RX4_SCL1)
ESP_TX: ESP1.2, U21.24 (17_A3_TX4_SDA1)
GND: 5k_21.1, 20k_21.1, 47k_22.2, CAN1.1, CAN2.1, DC_22.1, ESP1.1, IMU1.7, J2.3, J2.6, J2.9, J2.12, J2.15, J2.18, Q21.2 (S), S21.1, U21.1 (GND), U21.17 (GND), U21.32 (GND); also elsewhere on the board
IMU_INT: IMU1.6, U21.27 (20_A6_TX5_LRCLK1)
LED1: D_RED21.2 (A), U21.4 (2_OUT2)
LED2: D_GRN21.2 (A), U21.5 (3_LRCLK2)
MISO: IMU1.2, U21.14 (12_MISO_MQSL)
MOSI: IMU1.4, U21.13 (11_MOSI_CTX1)
unnamed: CAN1.4, JP21.2 (B)
unnamed: CAN2.4, JP22.2 (B)
unnamed: D23.2 (A), DC_21.2, LS21.2, Q21.3 (D)
unnamed: 5k_21.2, D_GRN21.1 (K)
unnamed: 20k_21.2, D_RED21.1 (K)
unnamed: 1k_21.1, 47k_22.1, Q21.1 (G)
RC1: J2.1, U21.6 (4_BCLK2)
RC2: J2.4, U21.7 (5_IN2)
RC3: J2.7, U21.8 (6_OUT1D)
RC4: J2.10, U21.9 (7_RX2_OUT1A)
RC5: J2.13, U21.10 (8_TX2_IN1)
RC6: J2.16, U21.11 (9_OUT1C)
SCLK: IMU1.3, U21.20 (13_SCK_CRX1_LED)
SPEAKER: 1k_21.2, U21.21 (14_A0_TX3_SPDIF_OUT)

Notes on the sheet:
CAN2
IMU
V1.4
RC_PWM
Remove ESP32 -- export serial to separate module ESPs need to have a clock crystal to transmit Fix CAN to be more bullet proof Bigger / more accessible pushbutton Battery footprint blows How about a "activate" for ESCs?
Speaker driver • Gate driven low-side logic MOSFET • Drain = speaker node, Source = GND, Gate = control signal
CAN1
ESP32

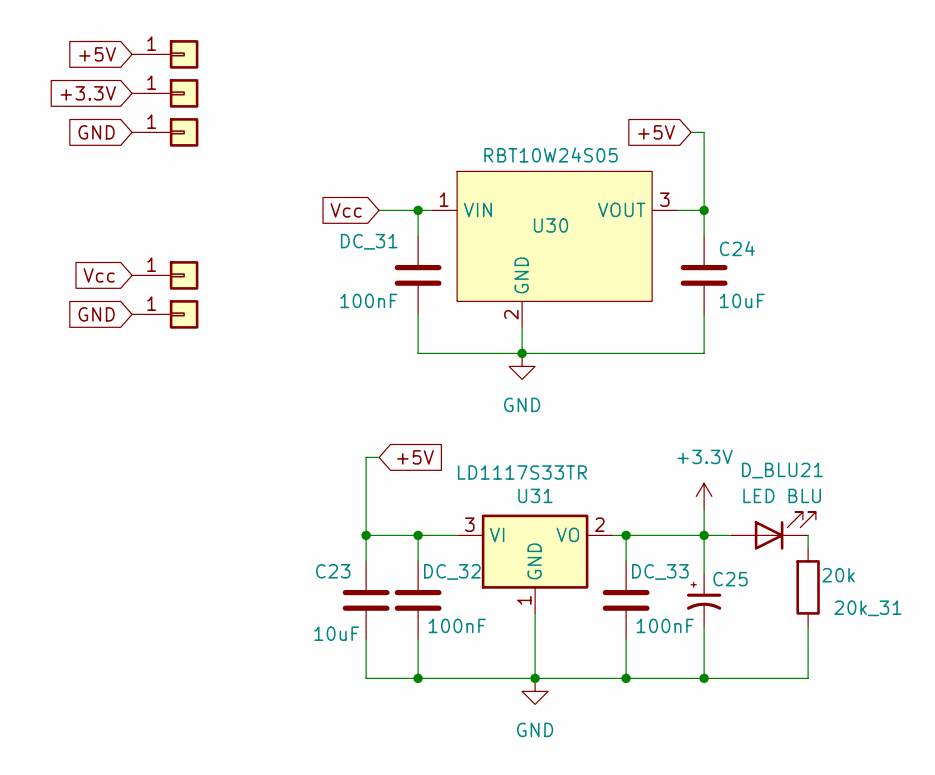
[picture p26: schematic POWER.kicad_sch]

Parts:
20k_31: 20k; R_0603_1608Metric; LCSC C4184
C23, C24: 10uF; C_0805_2012Metric; LCSC C96446
C25: T491A106K006AT; CP_EIA-3216-18_Kemet-A; LCSC C7171
DC_31, DC_32, DC_33: 100nF; C_0805_2012Metric; LCSC C342865
D_BLU21: LED BLU; LED_0603_1608Metric; LCSC APT1608QBC/D
J21, J22, J23: Conn_01x01; PinSocket_1x01_P2.54mm_Vertical
J24, J25: Conn_01x01; SolderWire-2sqmm_1x01_D2mm_OD3.9mm
U30: RBT10W24S05; 12_DCDC_5
U31: LD1117S33TR; SOT-223-3_TabPin2

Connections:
+3.3V: C25.1, DC_33.1, D_BLU21.2 (A), J23.1, U31.2 (VO); also elsewhere on the board
+5V: C23.1, C24.1, DC_32.1, J22.1, U30.3 (VOUT), U31.3 (VI); also elsewhere on the board
GND: 20k_31.1, C23.2, C24.2, C25.2, DC_31.2, DC_32.2, DC_33.2, J21.1, J25.1, U30.2 (GND), U31.1 (GND); also elsewhere on the board
unnamed: 20k_31.2, D_BLU21.1 (K)
Vcc: DC_31.1, J24.1, U30.1 (VIN)

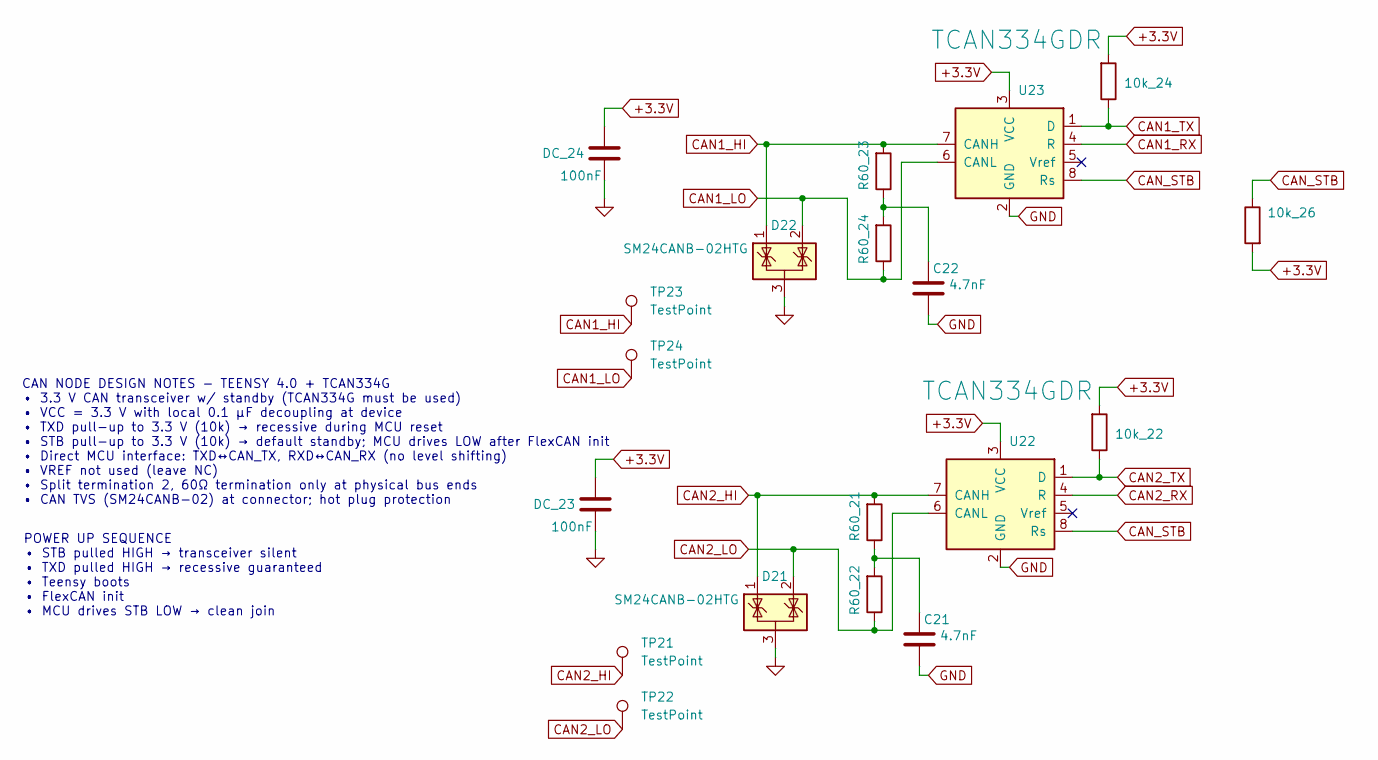
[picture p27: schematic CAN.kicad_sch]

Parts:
10k_22, 10k_24, 10k_26: 10k; R_0603_1608Metric; LCSC C25804
C21, C22: 4.7nF; C_0603_1608Metric
D21, D22: SM24CANB-02HTG; SOT95P230X117-3N
DC_23, DC_24: 100nF; C_0603_1608Metric
R60_21, R60_22, R60_23, R60_24: 60; R_0603_1608Metric; LCSC C17437
TP21, TP22, TP23, TP24: TestPoint; PinSocket_1x01_P2.54mm_Vertical
U22, U23: TCAN334GDR; SOIC-8_3.9x4.9mm_P1.27mm; LCSC C6952

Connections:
+3.3V: 10k_22.2, 10k_24.2, 10k_26.2, DC_23.1, DC_24.1, U22.3 (VCC), U23.3 (VCC); also elsewhere on the board
CAN1_HI: D22.1 (K), R60_23.2, TP23.1, U23.7 (CANH); also elsewhere on the board
CAN1_LO: D22.2 (K), R60_24.1, TP24.1, U23.6 (CANL); also elsewhere on the board
CAN1_RX: U23.4 (R); also elsewhere on the board
CAN1_TX: 10k_24.1, U23.1 (D); also elsewhere on the board
CAN2_HI: D21.1 (K), R60_21.2, TP21.1, U22.7 (CANH); also elsewhere on the board
CAN2_LO: D21.2 (K), R60_22.1, TP22.1, U22.6 (CANL); also elsewhere on the board
CAN2_RX: U22.4 (R); also elsewhere on the board
CAN2_TX: 10k_22.1, U22.1 (D); also elsewhere on the board
CAN_STB: 10k_26.1, U22.8 (Rs), U23.8 (Rs); also elsewhere on the board
GND: C21.2, C22.2, D21.3 (A), D22.3 (A), DC_23.2, DC_24.2, U22.2 (GND), U23.2 (GND); also elsewhere on the board
unnamed: C21.1, R60_21.1, R60_22.2
unnamed: C22.1, R60_23.1, R60_24.2

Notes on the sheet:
CAN NODE DESIGN NOTES - TEENSY 4.0 + TCAN334G • 3.3 V CAN transceiver w/ standby (TCAN334G must be used) • VCC = 3.3 V with local 0.1 µF decoupling at device • TXD pull-up to 3.3 V (10k) → recessive during MCU reset • STB pull-up to 3.3 V (10k) → default standby; MCU drives LOW after FlexCAN init •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
POWER UP SEQUENCE • STB pulled HIGH → transceiver silent • TXD pulled HIGH → recessive guaranteed • Teensy boots • FlexCAN init • MCU drives STB LOW → clean join

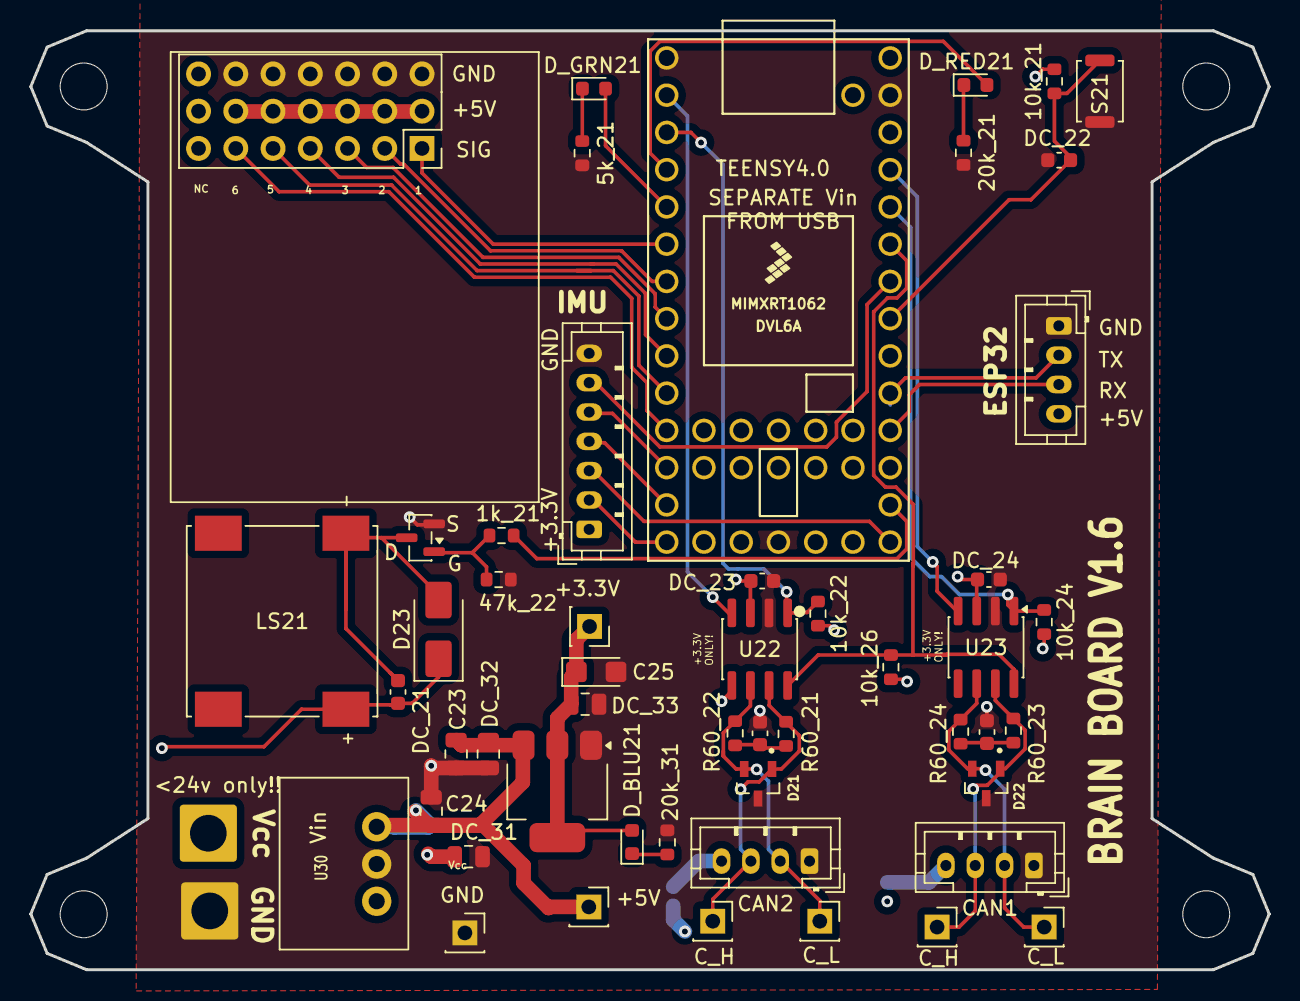
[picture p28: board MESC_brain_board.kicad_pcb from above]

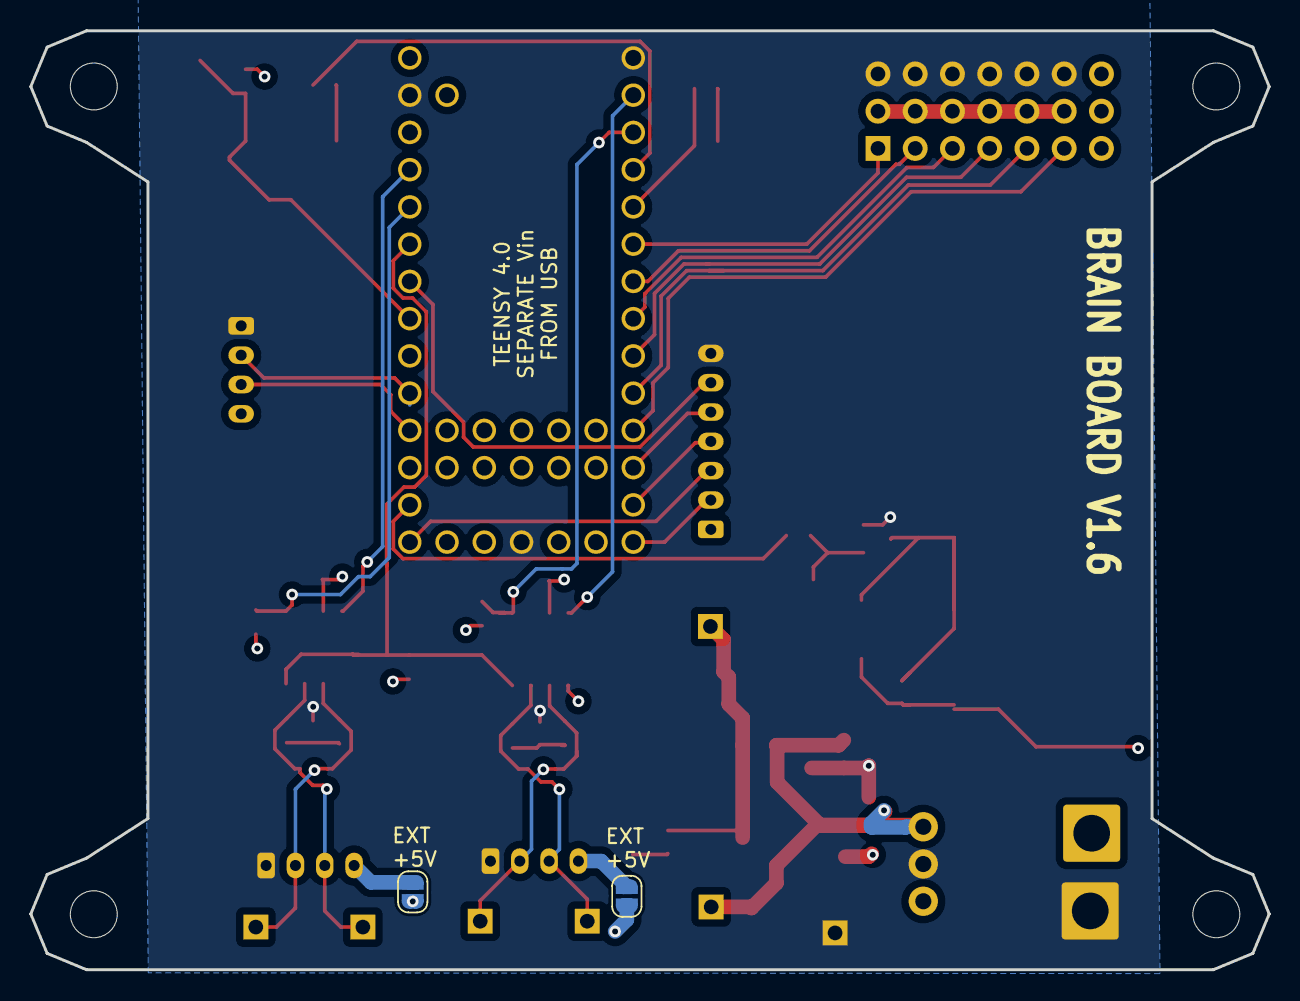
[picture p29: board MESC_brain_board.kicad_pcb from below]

Board: 4 copper layers, 84.5 x 64.0 mm, 55 parts (2 on the bottom side), 39 nets.

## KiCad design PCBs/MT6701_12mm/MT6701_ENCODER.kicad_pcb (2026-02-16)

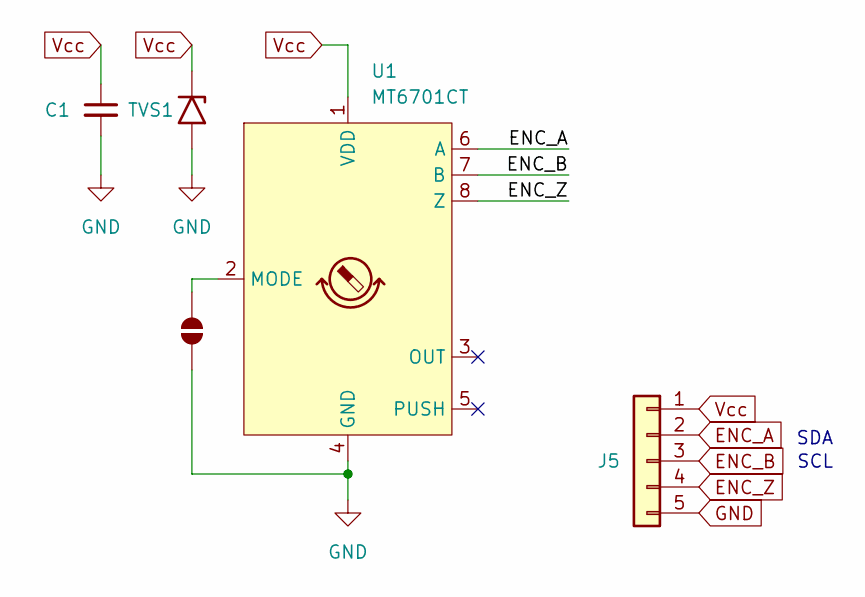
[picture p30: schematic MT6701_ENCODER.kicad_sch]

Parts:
C1: C_Small; C_0603_1608Metric
J5: Conn_01x05; PinSocket_1x05_P2.54mm_Vertical
JP1: SolderJumper_2_Open; SolderJumper-2_P1.3mm_Open_RoundedPad1.0x1.5mm
TVS1: SMFJ6.0A / SMFJ6.0CA; C_0805_2012Metric
U1: MT6701CT; SO-8_3.9x4.9mm_P1.27mm

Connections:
ENC_A: J5.2, U1.6 (A)
ENC_B: J5.3, U1.7 (B)
ENC_Z: J5.4, U1.8 (Z)
GND: C1.2, J5.5, JP1.2 (B), TVS1.2 (A2), U1.4 (GND)
unnamed: JP1.1 (A), U1.2 (MODE)
Vcc: C1.1, J5.1, TVS1.1 (A1), U1.1 (VDD)

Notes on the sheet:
SDA
SCL

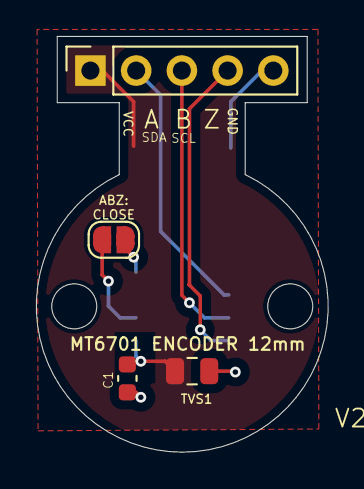
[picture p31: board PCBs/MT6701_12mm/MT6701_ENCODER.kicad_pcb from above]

Board: 2 copper layers, 16.2 x 23.1 mm, 5 parts (1 on the bottom side), 6 nets.

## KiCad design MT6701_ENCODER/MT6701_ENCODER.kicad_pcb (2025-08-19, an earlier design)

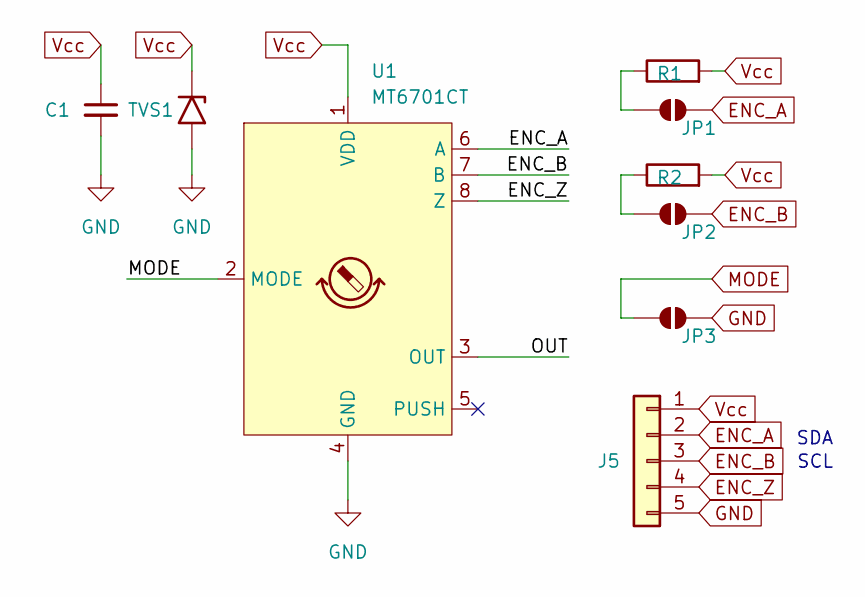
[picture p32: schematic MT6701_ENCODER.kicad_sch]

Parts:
C1: C_Small; C_0603_1608Metric
J5: Conn_01x05; PinHeader_1x05_P2.54mm_Vertical
JP1, JP2, JP3: SolderJumper_2_Open; SolderJumper-2_P1.3mm_Open_RoundedPad1.0x1.5mm
R1, R2: R; R_0603_1608Metric
TVS1: SMFJ6.0A / SMFJ6.0CA; C_0805_2012Metric
U1: MT6701CT; SO-8_3.9x4.9mm_P1.27mm

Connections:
/OUT: U1.3 (OUT)
ENC_A: J5.2, JP1.2 (B), U1.6 (A)
ENC_B: J5.3, JP2.2 (B), U1.7 (B)
ENC_Z: J5.4, U1.8 (Z)
GND: C1.2, J5.5, JP3.2 (B), TVS1.2 (A2), U1.4 (GND)
MODE: JP3.1 (A), U1.2 (MODE)
unnamed: JP1.1 (A), R1.1
unnamed: JP2.1 (A), R2.1
Vcc: C1.1, J5.1, R1.2, R2.2, TVS1.1 (A1), U1.1 (VDD)

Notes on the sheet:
SDA
SCL

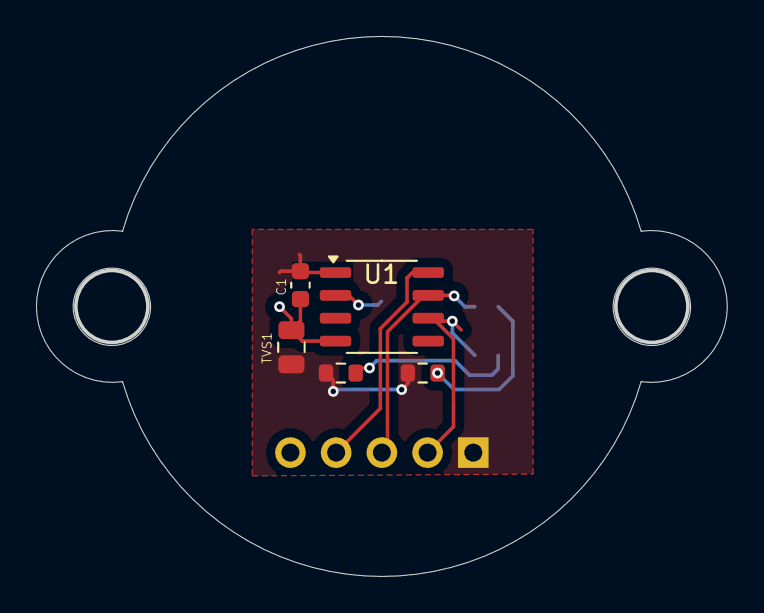
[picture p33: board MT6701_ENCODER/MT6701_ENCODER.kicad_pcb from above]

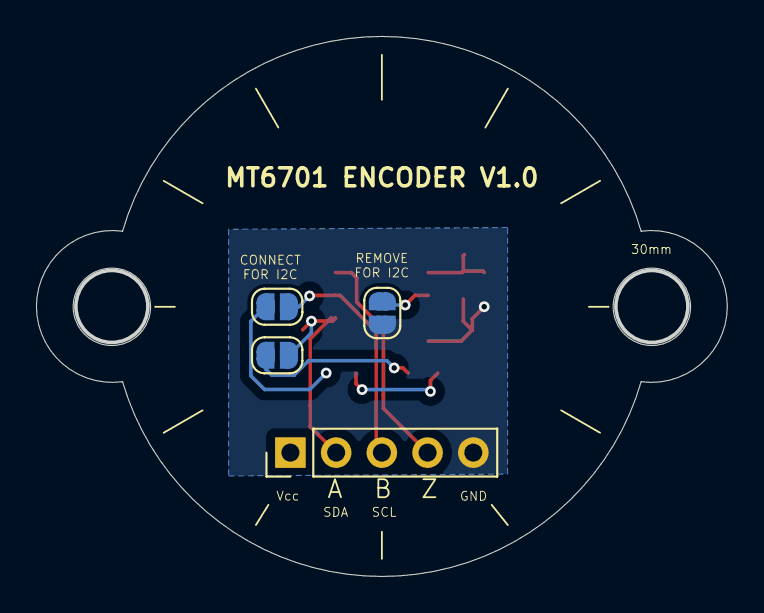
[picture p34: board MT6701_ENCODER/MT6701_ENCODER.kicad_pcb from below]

Board: 4 copper layers, 38.4 x 30.0 mm, 9 parts (4 on the bottom side), 8 nets.

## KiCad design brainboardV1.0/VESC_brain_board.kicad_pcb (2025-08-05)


Board: 4 copper layers, 90.5 x 68.6 mm, 50 parts (0 on the bottom side), 48 nets.

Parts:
1k_1, 10k_1, 10k_4, 10k_5, 10k_7, 10k_8: 10k; R_0603_1608Metric
1k_21, 1k_22: 1k; R_0603_1608Metric
20k_1, 20k_2, 20k_3: 20k; R_0603_1608Metric
90k_1: 90k; R_0603_1608Metric
C21: 10uF; C_0805_2012Metric
C22: C_Polarized_Small_US; CP_EIA-3216-18_Kemet-A
CAN1: Conn_01x04; JST_PH_B4B-PH-K_1x04_P2.00mm_Vertical
D22: BAT54S; SOT-23-3
DC_1, DC_2, DC_3, DC_4, DC_6: 100nF; C_0603_1608Metric
DC_5: 10uF; C_0805_2012Metric
D_BLU1: LED BLU; LED_0603_1608Metric
D_BLU2: BLUE; LED_0603_1608Metric
D_GRN1: LED GRN; LED_0603_1608Metric
D_RED1: LED RED; LED_0603_1608Metric
J1: Conn_01x18; my_PinSocket_3x07_P2.54mm_Vertical
J12, J13, J15: Conn_01x03; PinHeader_1x03_P2.54mm_Vertical
J14: SERIAL1; PinHeader_1x04_P2.54mm_Vertical
J21, J22, J23: Conn_01x01; PinSocket_1x01_P2.54mm_Vertical
JP1: SolderJumper_3_Open; SolderJumper-3_P1.3mm_Open_Pad1.0x1.5mm
LS1: Speaker; SPKR_CDS-13138-SMT-TR
MP1: Conn_01x08; PinSocket_1x08_P2.54mm_Vertical
Q1: my_BC337; SOT-23
R20k_4: 20k; R_0603_1608Metric
R_120: 120; R_0603_1608Metric
S1: TL3342F160QG; SW_SPST_B3SL-1022P
S11, S12: TL3342F160QG; SW_Push_SPST_NO_Alps_SKRK
SW_SPDT21: SW_SPDT; SW_NKK_BB15AH
U1: TJA1050T/CM,118; SOIC-8_3.9x4.9mm_P1.27mm
U2: Teensy4.0; Teensy40
U11: ESP32-WROOM-32D
U21: LD1117S18TR_SOT223; SOT-223-3_TabPin2
VESC1, VESC2: Conn_01x08; JST_PH_B8B-PH-K_1x08_P2.00mm_Vertical

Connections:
+3.3V: 10k_4.2, 10k_5.2, 10k_8.2, C22.1, D22.2, DC_5.2, DC_6.1, D_BLU1.2 (A), J15.3, J22.1, JP1.3 (B), MP1.1, U1.3 (VCC), U11.2 (VDD), U21.2 (VO)
+5V: C21.1, DC_2.1, J1.2, J1.5, J1.8, J1.11, J1.14, J1.17, J15.1, J21.1, JP1.1 (A), LS1.1, SW_SPDT21.1 (A), U2.33 (VIN), U21.3 (VI)
/CAN_RX: U1.4 (R), U2.30 (23_A9_CRX1_MCLK1)
/CAN_TX: U1.1 (D), U2.29 (22_A8_CTX1)
/MPU6050_SCL: MP1.3, U2.26 (19_A5_SCL0)
/MPU6050_SDA: MP1.4, U2.25 (18_A4_SDA0)
BUTTON: 10k_8.1, DC_1.2, S1.2, U2.24 (17_A3_TX4_SDA1)
CAN_HI: CAN1.3, R_120.2, U1.7 (CANH)
CAN_LO: CAN1.2, R_120.1, U1.6 (CANL)
ESP_EN: 10k_4.1, DC_3.2, S11.2, U11.3 (EN)
ESP_RX: J12.3, U2.2 (0_RX1_CRX2_CS1)
ESP_RX_OUT: J12.1, J14.2
ESP_TX: J13.3, U2.3 (1_TX1_CTX2_MISO1)
ESP_TX_OUT: J13.1, J14.3
GND: 10k_1.2, 10k_7.2, 20k_1.1, 20k_2.1, 20k_3.1, C21.2, C22.2, CAN1.1, D22.1, DC_1.1, DC_3.1, DC_4.1, DC_5.1, DC_6.2, J1.3, J1.6, J1.9, J1.12, J1.15, J1.18, J14.4, J23.1, MP1.2, Q1.2 (E), R20k_4.1, S1.1, S11.1, S12.1, U1.2 (GND), U2.1 (GND), U2.17 (GND), U2.32 (GND), U11.1 (GND), U11.15 (GND), U11.38 (GND), U21.1 (GND), VESC1.3, VESC2.3
IO0: 10k_5.1, DC_4.2, S12.2, U11.25 (IO0)
LED1: D_RED1.2 (A), U2.4 (2_OUT2)
LED2: D_GRN1.2 (A), U2.5 (3_LRCLK2)
unnamed: CAN1.4, JP1.2 (C)
unnamed: 20k_3.2, D_BLU1.1 (K)
unnamed: D_BLU2.2 (A), U11.24 (IO2)
unnamed: D_BLU2.1 (K), R20k_4.2
unnamed: 20k_2.2, D_GRN1.1 (K)
unnamed: 20k_1.2, D_RED1.1 (K)
unnamed: 1k_21.2, J12.2
unnamed: 1k_22.2, J13.2
unnamed: J14.1, J15.2
unnamed: 1k_1.1, Q1.1 (B)
unnamed: DC_2.2, LS1.2, Q1.3 (C)
unnamed: 10k_1.1, U1.8 (Rs)
RC_Mode: J1.7, U2.9 (7_RX2_OUT1A)
RC_Steering: J1.1, U2.11 (9_OUT1C)
RC_Throttle: J1.4, U2.10 (8_TX2_IN1)
RC_X: J1.10, U2.8 (6_OUT1D)
RC_Y: J1.13, U2.7 (5_IN2)
RC_Z: J1.16, U2.6 (4_BCLK2)
SPEAKER: 1k_1.2, U2.20 (13_SCK_CRX1_LED)
U0RXD: 1k_21.1, U11.34 (RXD0/IO3)
U0TXD: 1k_22.1, U11.35 (TXD0/IO1)
VESC1_ADC2: U2.13 (11_MOSI_CTX1), VESC1.7
VESC1_EN: U2.12 (10_CS_MQSR), VESC1.8
VESC1_TX: U2.14 (12_MISO_MQSL), VESC1.6
VESC1_VCC: 90k_1.1, VESC1.2
VESC2_ADC2: U2.22 (15_A1_RX3_SPDIF_IN), VESC2.7
VESC2_EN: U2.21 (14_A0_TX3_SPDIF_OUT), VESC2.8
VESC2_TX: U2.23 (16_A2_RX4_SCL1), VESC2.6
VESC_+5V: SW_SPDT21.2 (B), VESC1.1, VESC2.1
VSENSE: 10k_7.1, 90k_1.2, D22.3, U2.28 (21_A7_RX5_BCLK1)

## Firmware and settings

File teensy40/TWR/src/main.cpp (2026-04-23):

#include <FlexCAN_T4.h>
#include "LED.h"
#include <ArduinoJson.h>
#include <ctype.h>
#include <math.h>
#include <stddef.h>
#include <string.h>
#include <SerialTransfer.h>
#include "main.h"
#include "pushbutton.h"
#include "tone_player.h"
#include "tones.h"
#include "ICM42688.h"
#include "ESC.h"
#include "CAN_helper.h"
#include "supervisor.h"
#include "test_can_transmit_mode.h"
#include "balance_TWR_mode.h"
#include "balance_debug_mode.h"
#include "console_commands.h"
#include "telemetry_link.h"
#include "IMU_helper.h"

// Compile-time A/B selector for balance mode entry routing.
// 0 -> enter normal balance_TWR_mode()
// 1 -> enter balance_debug_mode() clone
#ifndef BALANCE_USE_DEBUG_MODE
#define BALANCE_USE_DEBUG_MODE 0
#endif

// ---------------------- Setup / Loop -----------------------
IntervalTimer g_ctrlTimer;
Supervisor_typedef supervisor;

const char* esc_names[]   = {"left", "right"};
const uint16_t esc_ids[]  = {11, 12}; // node_ids of the ESCs
const uint8_t rc_pins[]   = {RC_INPUT1, RC_INPUT2, RC_INPUT3};
static constexpr uint8_t RC_PIN_COUNT = sizeof(rc_pins) / sizeof(rc_pins[0]);


// -------------------- CAN Communication --------------------
FlexCAN_T4<CAN1, RX_SIZE_256, TX_SIZE_16> Can1;
FlexCAN_T4<CAN2, RX_SIZE_256, TX_SIZE_16> Can2;
CANBuffer canRxBuf1;  // CAN1 software RX queue
CANBuffer canRxBuf2;  // CAN2 software RX queue

// CAN reliability improvement:
// Push RX frames from FIFO ISR callbacks into software queues immediately.
static void can1_on_receive(const CAN_message_t &msg) {
  canNoteBusRead(1u);
  canNotePosvelIngress(msg);
  if (!canBufferPush(canRxBuf1, msg, 1u)) {
    canNoteRxOverflow();
  }
}

static void can2_on_receive(const CAN_message_t &msg) {
  canNoteBusRead(2u);
  canNotePosvelIngress(msg);
  if (!canBufferPush(canRxBuf2, msg, 2u)) {
    canNoteRxOverflow();
  }
}

// -------------------- Tone / Pushbutton --------------------
static TonePlayer g_tone;
static constexpr uint32_t BALANCE_EXIT_BEEP_HZ = 2200u;
static constexpr uint32_t BALANCE_EXIT_BEEP_MS = 30u;
static constexpr uint32_t BALANCE_EXIT_BEEP_GAP_MS = 0u;
PushButton g_button(PUSHBUTTON_PIN, true, 50000u);
ICM42688 imu(SPI, CS_PIN);
static constexpr uint32_t CAN_POSVEL_RX_TIMEOUT_US = 400000u;
static constexpr uint32_t CAN_TEST_RUN_DEFAULT_US = 30000000u;  // 30 seconds
static constexpr uint32_t BALANCE_BUTTON_RUN_US = 0u;  // 0 = no auto-timeout
static constexpr uint32_t BALANCE_BUTTON_STOP_GUARD_US = 800000u; // Ignore stop press for first 0.8 s.
static constexpr uint16_t CAL_KICKSTAND_SAMPLES = 100u;
static constexpr float CAL_TARGET_DELTA_RAD = -1.270f;
static constexpr float CAL_TARGET_TOL_RAD = 0.020f;
static constexpr float CAL_RATE_MAX_RAD_S = 0.10f;
static constexpr uint32_t CAL_HOLD_US = 300000u;
static constexpr uint32_t CAL_AX_PRINT_PERIOD_US = 20000u; // 50 Hz while target reached
static constexpr uint32_t IDLE_LONG_HOLD_US = 2000000u; // 2 seconds
static constexpr uint32_t SERIALTRANSFER_SEND_PERIOD_US = 10000u; // 100 Hz
static constexpr uint32_t SERIALTRANSFER_ACK_TIMEOUT_US = 20000u;
static uint32_t g_balance_mode_enter_us = 0u;
static SupervisorMode g_prev_mode_for_exit_tweet = SUP_MODE_IDLE;
static SupervisorMode g_prev_mode_for_telem_flush = SUP_MODE_IDLE;
static bool g_telem_flush_after_balance_twr = false;
static uint32_t g_telem_flush_start_us = 0u;
static uint32_t g_telem_flush_start_packets = 0u;
static uint32_t g_telem_flush_start_bytes = 0u;
static uint16_t g_cal_kickstand_count = 0u;
static float g_cal_kickstand_sum = 0.0f;
static float g_cal_kickstand_pitch = 0.0f;
static bool g_cal_kickstand_ready = false;
static float g_cal_theta_eq_target = 0.0f;
static uint32_t g_cal_hold_start_us = 0u;
static bool g_cal_target_in_window = false;
static bool g_cal_target_reached_announced = false;
static uint32_t g_cal_last_ax_print_us = 0u;
static bool g_idle_long_hold_tracking = false;
static uint32_t g_idle_long_hold_start_us = 0u;
static bool g_idle_long_hold_fired = false;
static SerialTransfer g_telem_transfer;
static uint32_t g_telem_transfer_last_send_us = 0u;
static uint32_t g_telem_transfer_seq = 0u;
static uint32_t g_telem_flush_last_tx_us = 0u;
static uint32_t g_telem_flush_sent_packets = 0u;
static uint32_t g_telem_flush_acked_packets = 0u;
static uint32_t g_telem_flush_retries = 0u;
static uint32_t g_telem_flush_outstanding_seq = 0u;
static bool g_telem_flush_waiting_ack = false;
static TelemetryPacket g_telem_flush_outstanding_pkt = {};
// Temporary debug stream: while in balance mode, print raw accel vs filtered pitch.
static constexpr bool TEMP_PRINT_BALANCE_IMU_ENABLE = false;
static constexpr uint32_t TEMP_PRINT_BALANCE_IMU_PERIOD_US = 10000u; // 100 Hz
static uint32_t g_last_balance_imu_print_us = 0u;
// Runtime decimated printing can perturb timing; keep off for measurement runs.
// Uncomment to ignore pushbutton state transitions.
// #define PB_OVERRIDE

static inline void reset_calibration_state() {
  g_cal_kickstand_count = 0u;
  g_cal_kickstand_sum = 0.0f;
  g_cal_kickstand_pitch = 0.0f;
  g_cal_kickstand_ready = false;
  g_cal_theta_eq_target = 0.0f;
  g_cal_hold_start_us = 0u;
  g_cal_target_in_window = false;
  g_cal_target_reached_announced = false;
  g_cal_last_ax_print_us = 0u;
}

static uint16_t crc16_ccitt(const uint8_t *data, size_t len) {
  uint16_t crc = 0xFFFFu;
  if (data == nullptr) return crc;
  for (size_t i = 0u; i < len; ++i) {
    crc ^= (uint16_t)data[i] << 8;
    for (uint8_t b = 0u; b < 8u; ++b) {
      if ((crc & 0x8000u) != 0u) {
        crc = (uint16_t)((crc << 1) ^ 0x1021u);
      } else {
        crc <<= 1;
      }
    }
  }
  return crc;
}

static void sendDatum(const TelemetryPacket &pkt) {
  g_telem_transfer.sendDatum(pkt);
}

struct __attribute__((packed)) TelemetryAck {
  uint32_t seq;
  uint16_t code;
  uint16_t reserved;
};

static void telemetry_serialtransfer_flush_tick(uint32_t now_us) {
#if TELEMETRY_SERIALTRANSFER_TX_ENABLE
  // Drain inbound ACKs first.
  static constexpr uint8_t MAX_RX_PER_TICK = 8u;
  for (uint8_t i = 0u; i < MAX_RX_PER_TICK; ++i) {
    if (!g_telem_transfer.available()) break;

    if (g_telem_transfer.bytesRead == sizeof(TelemetryAck)) {
      TelemetryAck ack = {};
      uint16_t rx_size = 0u;
      rx_size = g_telem_transfer.rxObj(ack, rx_size);
      if (rx_size == sizeof(TelemetryAck) &&
          g_telem_flush_waiting_ack &&
          ack.seq == g_telem_flush_outstanding_seq) {
        g_telem_flush_waiting_ack = false;
        g_telem_flush_acked_packets++;
      }
    }
  }

  if (!g_telem_flush_after_balance_twr || supervisor.mode != SUP_MODE_IDLE) return;

  if (g_telem_flush_waiting_ack) {
    if ((uint32_t)(now_us - g_telem_flush_last_tx_us) >= SERIALTRANSFER_ACK_TIMEOUT_US) {
      sendDatum(g_telem_flush_outstanding_pkt);
      g_telem_flush_last_tx_us = now_us;
      g_telem_flush_retries++;
    }
    return;
  }

  TelemetryPacket next_pkt = {};
  if (telemetry_pop_next_packet(&next_pkt)) {
    g_telem_flush_outstanding_pkt = next_pkt;
    g_telem_flush_outstanding_seq = next_pkt.seq;
    sendDatum(g_telem_flush_outstanding_pkt);
    g_telem_flush_last_tx_us = now_us;
    g_telem_flush_sent_packets++;
    g_telem_flush_waiting_ack = true;
    return;
  }

  g_telem_flush_after_balance_twr = false;
  const uint32_t end_packets = telemetry_pending_packets();
  const uint32_t end_bytes = telemetry_pending_bytes();
  const uint32_t elapsed_us = (uint32_t)(micros() - g_telem_flush_start_us);
  Serial.printf(
      "{\"cmd\":\"TELEM_FLUSH_END\",\"driver\":\"SerialTransfer\",\"packet_size_bytes\":%lu,\"start_packets\":%lu,\"start_bytes\":%lu,\"remaining_packets\":%lu,\"remaining_bytes\":%lu,\"sent_packets\":%lu,\"acked_packets\":%lu,\"retries\":%lu,\"elapsed_us\":%lu}\r\n",
      (unsigned long)telemetry_packet_size_bytes(),
      (unsigned long)g_telem_flush_start_packets,
      (unsigned long)g_telem_flush_start_bytes,
      (unsigned long)end_packets,
      (unsigned long)end_bytes,
      (unsigned long)g_telem_flush_sent_packets,
      (unsigned long)g_telem_flush_acked_packets,
      (unsigned long)g_telem_flush_retries,
      (unsigned long)elapsed_us);
#else
  (void)now_us;
#endif
}

static inline void telemetry_serialtransfer_send_100hz(uint32_t now_us) {
#if TELEMETRY_SERIALTRANSFER_TX_ENABLE
  if ((uint32_t)(now_us - g_telem_transfer_last_send_us) < SERIALTRANSFER_SEND_PERIOD_US) return;
  g_telem_transfer_last_send_us = now_us;

  TelemetryPacket pkt = {};
  pkt.seq = ++g_telem_transfer_seq;
  pkt.timestamp_us = now_us;
  pkt.type = TELEMETRY_TYPE_FAST;
  pkt.status_flags = 0u;
  pkt.payload[0] = (supervisor.esc_count > 0u) ? supervisor.esc[0].state.bus_voltage : NAN;
  pkt.payload[1] = (supervisor.esc_count > 1u) ? supervisor.esc[1].state.bus_voltage : NAN;
  pkt.state_bits = (uint32_t)supervisor.mode;
  pkt.footer = TELEMETRY_PACKET_FOOTER;
  pkt.checksum = crc16_ccitt(reinterpret_cast<const uint8_t*>(&pkt),
                             offsetof(TelemetryPacket, checksum));
  sendDatum(pkt);
#else
  (void)now_us;
#endif
}

static inline bool is_balance_mode(SupervisorMode m) {
  return (m == SUP_MODE_BALANCE_HOLD) ||
         (m == SUP_MODE_BALANCE_TWR) ||
         (m == SUP_MODE_BALANCE_DEBUG);
}

static inline SupervisorMode selected_balance_entry_mode() {
#if BALANCE_USE_DEBUG_MODE
  return SUP_MODE_BALANCE_DEBUG;
#else
  return SUP_MODE_BALANCE_HOLD;
#endif
}

static inline void dump_selected_balance_mode_on_exit(SupervisorMode mode, const char *reason) {
  if (mode == SUP_MODE_BALANCE_DEBUG) {
    balance_debug_dump_on_mode_exit(reason);
  } else {
    balance_TWR_dump_on_mode_exit(reason);
  }
}

static const char* mode_to_str(SupervisorMode mode) {
  switch (mode) {
    case SUP_MODE_IDLE: return "SUP_MODE_IDLE";
    case SUP_MODE_CALIBRATE: return "SUP_MODE_CALIBRATE";
    case SUP_VERIFY_ANGLE: return "SUP_VERIFY_ANGLE";
    case SUP_MODE_BALANCE_HOLD: return "SUP_MODE_BALANCE_HOLD";
    case SUP_MODE_BALANCE_TWR: return "SUP_MODE_BALANCE_TWR";
    case SUP_MODE_BALANCE_DEBUG: return "SUP_MODE_BALANCE_DEBUG";
    case SUP_MODE_TEST_CAN: return "SUP_MODE_TEST_CAN";
    default: return "SUP_MODE_UNKNOWN";
  }
}

// --------------------- LED instances -----------------------
static LEDCtrl g_led_red;
LEDCtrl g_led_green;

void setup() {

  Serial.begin(921600);
  while (!Serial && millis() < 1500) {}
  // CAN2 uses pins 0/1 on Teensy 4.0, so avoid Serial1 on those same pins.
#if TELEMETRY_SERIALTRANSFER_TX_ENABLE
  // Initialize telemetry queues used by balance_TWR_mode logging.
  telemetry_link_init(Serial4, TELEMETRY_SERIALTRANSFER_BAUD);
  Serial4.begin(TELEMETRY_SERIALTRANSFER_BAUD);
  g_telem_transfer.begin(Serial4, false);
#if TELEMETRY_SERIALTRANSFER_CONTINUOUS_TX_ENABLE
  Serial.printf("{\"cmd\":\"TELEM_LINK_CFG\",\"enabled\":1,\"driver\":\"SerialTransfer\",\"port\":\"Serial4\",\"baud\":%lu,\"mode\":\"continuous\",\"rate_hz\":100}\r\n",
                (unsigned long)TELEMETRY_SERIALTRANSFER_BAUD);
#else
  Serial.printf("{\"cmd\":\"TELEM_LINK_CFG\",\"enabled\":1,\"driver\":\"SerialTransfer\",\"port\":\"Serial4\",\"baud\":%lu,\"mode\":\"balance_flush_on_idle\"}\r\n",
                (unsigned long)TELEMETRY_SERIALTRANSFER_BAUD);
#endif
#elif TELEMETRY_LINK_ENABLE
  telemetry_link_init(Serial4, TELEMETRY_LINK_BAUD);
  Serial.printf("{\"cmd\":\"TELEM_LINK_CFG\",\"enabled\":1,\"port\":\"Serial4\",\"baud\":%lu}\r\n",
                (unsigned long)TELEMETRY_LINK_BAUD);
#else
  Serial.printf("{\"cmd\":\"TELEM_LINK_CFG\",\"enabled\":0}\r\n");
#endif

  // LEDs / Pushbutton / Tone
  led_init(&g_led_red,   LED1_PIN, LED_BLINK_SLOW);
  led_init(&g_led_green, LED2_PIN, LED_BLINK_FAST);
  tone_init(&g_tone, SPEAKER_PIN);

  // ---- IMU Setup (hybrid: TWR filter behavior + vibration_test robustness) ----
  const IMUHelperInitResult imu_init = imu_helper_init(imu, CS_PIN, INT_PIN);
  if (!imu_init.ok) {
    Serial.printf("{\"cmd\":\"IMU_INIT_FAIL\",\"step\":\"%s\",\"status\":%d}\r\n",
                  imu_init.step,
                  imu_init.status);
    while (true) {
      delay(1000);
    }
  }

  // ---- CAN Setup ----
  // CAN1 default routing on Teensy 4.0: RX=pin 23, TX=pin 22.
  Can1.setRX(CAN1_PINSEL);
  Can1.setTX(CAN1_PINSEL);
  Can1.begin();
  Can1.setBaudRate(1000000);
  // CAN reliability improvement:
  // FIFO + IRQ receive path reduces loop-latency-induced drops.
  Can1.enableFIFO();
  Can1.enableFIFOInterrupt();
  Can1.onReceive(can1_on_receive);

  // CAN2 default routing on Teensy 4.0: RX=pin 0, TX=pin 1.
  Can2.setRX(CAN2_PINSEL);
  Can2.setTX(CAN2_PINSEL);
  Can2.begin();
  Can2.setBaudRate(1000000);
  // CAN reliability improvement:
  // Mirror CAN1 FIFO + IRQ setup so both buses have symmetric RX behavior.
  Can2.enableFIFO();
  Can2.enableFIFOInterrupt();
  Can2.onReceive(can2_on_receive);
  pinMode(CAN_STB, OUTPUT);
  digitalWrite(CAN_STB, LOW);

  init_supervisor(&supervisor,
                  2,           // esc_count -- FIX: dont hard code this number
                  esc_names,   // ESC names
                  esc_ids,     // ESC node IDs
                  rc_pins,     // RC pins
                  RC_PIN_COUNT); // RC count

  // Start in idle; require explicit serial command or pushbutton calibrate flow.
  supervisor.mode = SUP_MODE_IDLE;
  g_prev_mode_for_exit_tweet = supervisor.mode;
  g_prev_mode_for_telem_flush = supervisor.mode;
  reset_calibration_state();
  supervisor.user_total_us = 0;
  supervisor.user_tx_enable = true;
  supervisor.user_tx_period_us = 2000;  // default 500 Hz command TX
  canResetPosvelStats();
  canResetRuntimeStats();
  canRxBuf1.overflow_count = 0;
  canRxBuf2.overflow_count = 0;
  Serial.printf("{\"cmd\":\"CONSOLE_CFG\",\"enabled\":%d,\"echo\":%d,\"char_budget\":%lu}\r\n",
                SERIAL_CONSOLE_ENABLE ? 1 : 0,
                SERIAL_CONSOLE_ECHO ? 1 : 0,
                (unsigned long)SERIAL_CONSOLE_CHAR_BUDGET_PER_CALL);

  // ---- Control tick ISR ----
  g_ctrlTimer.priority(CONTROL_LOOP_PRIORITY);
  g_ctrlTimer.begin(controlLoop_isr, CONTROL_PERIOD_US);

}

void loop() {
  // -------- HIGH PRIORITY --------
  // Set to CONTROL_PERIOD_US = 1000 µs (1000 Hz).
  // NOTE: ESC POSVEL over CAN is expected around 500 Hz (about every 2 ms),
  // while this control loop runs at 1 kHz (every 1 ms). They are intentionally
  // asynchronous, so many control ticks will reuse the latest POSVEL sample.
  // TODO(balance): IQREQ command spacing is currently jittered (~2-3 ms in tests),
  // so balancing control must use measured dt/freshness, not fixed-period assumptions.
  // The system uses an ISR-driven scheduler to tell the main loop to go into controlLoop. 
  // ---
  while (true) {
    noInterrupts();
    const uint32_t pending = g_control_pending_ticks;
    if (pending == 0u) {
      interrupts();
      break;
    }
    g_control_pending_ticks = pending - 1u;
    interrupts();
    controlLoop(&supervisor, Can1, Can2);
  }

  // Tweet exactly once whenever balance mode exits.
  if (is_balance_mode(g_prev_mode_for_exit_tweet) &&
      !is_balance_mode(supervisor.mode)) {
    tone_start(&g_tone, BALANCE_EXIT_BEEP_HZ, BALANCE_EXIT_BEEP_MS, BALANCE_EXIT_BEEP_GAP_MS);
    Serial.printf("{\"cmd\":\"BALANCE_EXIT_TWEET\",\"from\":%d,\"to\":%d}\r\n",
                  (int)g_prev_mode_for_exit_tweet,
                  (int)supervisor.mode);
  }
  g_prev_mode_for_exit_tweet = supervisor.mode;

  // -------- CAN RX --------
  // ISR callbacks enqueue frames; events() dispatch drains hardware FIFOs.
  // ---
  imu_helper_poll(imu, supervisor, micros());

  CAN_message_t msg;
  // CAN reliability improvement:
  // Dispatch queued FlexCAN callbacks every loop so ISR-fed FIFO data drains promptly.
  const uint32_t can1_events_us = micros();
  canNoteEventsDispatch(1u, can1_events_us);
  Can1.events();
  const uint32_t can2_events_us = micros();
  canNoteEventsDispatch(2u, can2_events_us);
  Can2.events();
  uint8_t rx_bus = 0u;
  while (true) {
    bool popped_any = false;
    if (canBufferPop(canRxBuf1, msg, &rx_bus)) {
      handleCANMessage(msg, rx_bus);
      popped_any = true;
    }
    if (canBufferPop(canRxBuf2, msg, &rx_bus)) {
      handleCANMessage(msg, rx_bus);
      popped_any = true;
    }
    if (!popped_any) break;
  }

  uint32_t now_us = micros();
  uint32_t last_posvel_rx_us = canGetLastPosVelRxUs();
  bool posvel_rx_fresh = (last_posvel_rx_us != 0u) &&
                         ((uint32_t)(now_us - last_posvel_rx_us) <= CAN_POSVEL_RX_TIMEOUT_US);
  led_set_state(&g_led_red, posvel_rx_fresh ? LED_PULSE : LED_OFF);
  led_update(&g_led_red, now_us);

  const bool button_raw_pressed = (g_button.readRaw() == PB_PRESSED);
  if (button_raw_pressed) {
    if (!g_idle_long_hold_tracking) {
      g_idle_long_hold_tracking = true;
      g_idle_long_hold_start_us = now_us;
      g_idle_long_hold_fired = false;
    } else if (!g_idle_long_hold_fired &&
               ((uint32_t)(now_us - g_idle_long_hold_start_us) >= IDLE_LONG_HOLD_US)) {
      g_idle_long_hold_fired = true;
      if (is_balance_mode(supervisor.mode)) {
        dump_selected_balance_mode_on_exit(supervisor.mode, "button_long_hold");
      }
      supervisor.mode = SUP_MODE_IDLE;
      g_balance_mode_enter_us = 0u;
      supervisor.user_total_us = 0u;
      reset_calibration_state();
      start_idle_long_hold_song();
      Serial.printf("{\"cmd\":\"MODE\",\"source\":\"button\",\"mode\":\"SUP_MODE_IDLE\",\"reason\":\"button_long_hold\"}\r\n");
    }
  } else {
    g_idle_long_hold_tracking = false;
    g_idle_long_hold_fired = false;
  }

  if (supervisor.mode == SUP_MODE_CALIBRATE) {
    if (supervisor.imu.valid) {
      const float pitch_accel = imu_helper_pitch_accel_from_last_sample();
      if (!g_cal_kickstand_ready) {
        g_cal_kickstand_sum += pitch_accel;
        g_cal_kickstand_count++;
        if (g_cal_kickstand_count >= CAL_KICKSTAND_SAMPLES) {
          g_cal_kickstand_pitch = g_cal_kickstand_sum / (float)g_cal_kickstand_count;
          g_cal_theta_eq_target = g_cal_kickstand_pitch + CAL_TARGET_DELTA_RAD;
          g_cal_kickstand_ready = true;
          Serial.printf(
              "{\"cmd\":\"CALIBRATE_REF\",\"kickstand_pitch_rad\":%.6f,\"target_eq_rad\":%.6f,\"target_delta_rad\":%.6f,\"samples\":%u}\r\n",
              g_cal_kickstand_pitch,
              g_cal_theta_eq_target,
              CAL_TARGET_DELTA_RAD,
              (unsigned int)g_cal_kickstand_count);
        }
      } else {
        const float delta_from_kickstand = pitch_accel - g_cal_kickstand_pitch;
        const float eq_err_rad = pitch_accel - g_cal_theta_eq_target;
        const bool in_window = fabsf(eq_err_rad) <= CAL_TARGET_TOL_RAD;
        const bool low_energy = fabsf(supervisor.imu.pitch_rate) <= CAL_RATE_MAX_RAD_S;
        g_cal_target_in_window = in_window;

        if (in_window && !g_cal_target_reached_announced) {
          g_cal_target_reached_announced = true;
          balance_zero_cross_tweet();
          Serial.printf(
              "{\"cmd\":\"CAL_TARGET_REACHED\",\"pitch_accel_rad\":%.6f,\"kickstand_pitch_rad\":%.6f,\"delta_rad\":%.6f,\"target_delta_rad\":%.6f}\r\n",
              pitch_accel,
              g_cal_kickstand_pitch,
              delta_from_kickstand,
              CAL_TARGET_DELTA_RAD);
        }

        if (in_window && low_energy) {
          if (g_cal_hold_start_us == 0u) g_cal_hold_start_us = now_us;
          if ((uint32_t)(now_us - g_cal_hold_start_us) >= CAL_HOLD_US) {
            canRxBuf1.overflow_count = 0;
            canRxBuf2.overflow_count = 0;
            for (uint16_t i = 0; i < supervisor.esc_count; ++i) {
              supervisor.esc_alive_false_count[i] = 0u;
            }
            supervisor.user_tx_enable = true;
            supervisor.user_total_us = BALANCE_BUTTON_RUN_US;
            supervisor.mode = SUP_MODE_BALANCE_TWR;
            g_balance_mode_enter_us = now_us;
            balance_TWR_set_theta_reference(g_cal_theta_eq_target, 0.0f);
            balance_zero_cross_tweet();
            Serial.printf(
                "{\"cmd\":\"MODE\",\"source\":\"calibrate\",\"mode\":\"SUP_MODE_BALANCE_TWR\",\"theta_eq_rad\":%.6f,\"pitch_accel_rad\":%.6f,\"pitch_rate_rad_s\":%.6f,\"hold_ms\":%lu}\r\n",
                g_cal_theta_eq_target,
                pitch_accel,
                supervisor.imu.pitch_rate,
                (unsigned long)(CAL_HOLD_US / 1000u));
            reset_calibration_state();
          }
        } else {
          g_cal_hold_start_us = 0u;
        }
      }
    }
  }

  // LED2 behavior:
  // - Idle: OFF.
  // - Calibrate: ON only when near the zero-equilibrium target angle.
  // - Other modes: link-health indicator.
  if (supervisor.mode == SUP_MODE_IDLE) {
    led_set_state(&g_led_green, LED_OFF);
  } else if (supervisor.mode == SUP_MODE_CALIBRATE) {
    led_set_state(&g_led_green, g_cal_target_in_window ? LED_ON_CONTINUOUS : LED_OFF);
  } else {
    const bool can_link_ok = canRxBuf1.link_ok || canRxBuf2.link_ok;
    led_set_state(&g_led_green, can_link_ok ? LED_ON_CONTINUOUS : LED_BLINK_SLOW);
  }
  led_update(&g_led_green, now_us);
  tone_update(&g_tone, now_us);
  update_idle_long_hold_song();
  if (supervisor.mode == SUP_MODE_CALIBRATE) {
    update_calibrate_song();
  }
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

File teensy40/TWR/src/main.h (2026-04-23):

#ifndef MAIN_H
#define MAIN_H

#include <Arduino.h>
#include <IntervalTimer.h>
#include <FlexCAN_T4.h>

// ================= MESC CAN definitions =================
#define CAN_ID_IQREQ    0x001
#define TEENSY_NODE_ID  0x03 // sender (is this Teensy)

// ================= Peripherals =================
#define LED1_PIN        2
#define LED2_PIN        3
#define PUSHBUTTON_PIN  19
#define SPEAKER_PIN     14
#define CS_PIN          10
#define INT_PIN         20
#define CAN_STB         21   // Verify this pin drives the CAN2 transceiver standby on brain_board V1.6.
// FlexCAN_T4 setRX()/setTX() takes FLEXCAN_PINS enum, not literal GPIO numbers.
// For CAN1 on Teensy 4.0, DEF selects CAN1_RX=pin 23 and CAN1_TX=pin 22.
#define CAN1_PINSEL     DEF
// Set to 0 to fully disable CAN1 traffic during A/B tests (TX and RX on Teensy side).
#define CAN1_ENABLE     1
// For CAN2 on Teensy 4.0, DEF selects CAN2_RX=pin 0 and CAN2_TX=pin 1.
#define CAN2_PINSEL     DEF

// CAN RX path is fixed to ISR callback + events() dispatch.
#define CAN_RX_USE_ISR 1

// ================= Serial Console A/B =================
// 1 = parse interactive serial commands in low-priority loop.
// 0 = disable command parsing entirely (A/B timing test).
#ifndef SERIAL_CONSOLE_ENABLE
#define SERIAL_CONSOLE_ENABLE 1
#endif

// 1 = echo typed characters back to terminal during console parsing.
// 0 = no echo (keeps parser active but lighter).
#ifndef SERIAL_CONSOLE_ECHO
#define SERIAL_CONSOLE_ECHO 1
#endif

// Max number of serial bytes parsed per low-priority pass.
// 0 = unlimited; lower values reduce console-induced jitter for A/B tests.
#ifndef SERIAL_CONSOLE_CHAR_BUDGET_PER_CALL
#define SERIAL_CONSOLE_CHAR_BUDGET_PER_CALL 0u
#endif

// ================= ESP32 Telemetry Link =================
// Teensy 4.0 pins 16/17 map to Serial4 (RX4/TX4).
#ifndef TELEMETRY_LINK_ENABLE
#define TELEMETRY_LINK_ENABLE 1
#endif
#ifndef TELEMETRY_LINK_BAUD
#define TELEMETRY_LINK_BAUD 921600u
#endif

// SerialTransfer-based telemetry bridge mode (Teensy -> ESP32 over Serial4).
// Uses TelemetryPacket as the shared packed wire struct.
#ifndef TELEMETRY_SERIALTRANSFER_TX_ENABLE
#define TELEMETRY_SERIALTRANSFER_TX_ENABLE 1
#endif
#ifndef TELEMETRY_SERIALTRANSFER_BAUD
#define TELEMETRY_SERIALTRANSFER_BAUD 2000000u
#endif
#ifndef TELEMETRY_SERIALTRANSFER_CONTINUOUS_TX_ENABLE
#define TELEMETRY_SERIALTRANSFER_CONTINUOUS_TX_ENABLE 0
#endif

// Global compile-time safety gate for wheel command transmission.
// 0 = never send IQREQ torque frames from Teensy
// 1 = allow IQREQ torque TX (normal behavior)
#ifndef SEND_TORQUE
#define SEND_TORQUE 1
#endif

// ================= CAN TX routing =================
// Route each ESC node to exactly one physical CAN controller.
// This avoids writing every command on both buses.
#define CAN_TX_BUS_CAN1 1
#define CAN_TX_BUS_CAN2 2
#define CAN_TX_BUS_BOTH 3

// Current bench mapping:
// - node 11 uses CAN2
// - node 12 uses CAN1
#define ESC_NODE11_TX_BUS CAN_TX_BUS_CAN2
#define ESC_NODE12_TX_BUS CAN_TX_BUS_CAN1

static inline uint8_t can_tx_bus_for_node(uint8_t node_id) {
  if (node_id == 11u) return ESC_NODE11_TX_BUS;
  if (node_id == 12u) return ESC_NODE12_TX_BUS;
  return CAN_TX_BUS_BOTH;  // fallback for unknown nodes
}

// Short chirp used by balance mode when theta_tared crosses zero.
void balance_zero_cross_tweet(void);

// ================= RC PWM channels =================
#define RC_INPUT1       4
#define RC_INPUT2       5
#define RC_INPUT3       6
#define RC_INPUT4       7
#define RC_INPUT5       8
#define RC_INPUT6       9

#endif // MAIN_H

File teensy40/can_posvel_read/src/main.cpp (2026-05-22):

#include <Arduino.h>
#include <FlexCAN_T4.h>

/*
 * POSVEL reader / optional keepalive diagnostic.
 *
 * Important MESC behavior as tested on the current ESC firmware:
 * - The ESC POSVEL scheduler now uses a wrap-safe monotonic timebase, so
 *   autonomous CAN_ID_POSVEL publication no longer needs zero-IQREQ keepalive
 *   traffic to survive the old ~25.56 s F405 DWT cycle-counter wrap.
 * - Incoming zero-torque IQREQ frames can still be sent for sync experiments
 *   or older ESC firmware; the ESC keeps the IQREQ-triggered sync/nudge path.
 * - The TWR bench wiring uses both Teensy CAN controllers, with node routing
 *   that may place node 11 on CAN2. To avoid silent wrong-bus tests, this
 *   reader listens on CAN1 and CAN2 and sends optional IQREQ traffic on both.
 */
FlexCAN_T4<CAN1, RX_SIZE_256, TX_SIZE_16> Can1;
FlexCAN_T4<CAN2, RX_SIZE_256, TX_SIZE_16> Can2;

// --- Constants ---
#define CAN_ID_IQREQ 0x001
#define CAN_ID_POSVEL 0x2D0   // MESC POS/VEL ID
#define TEENSY_NODE_ID 0x03
#define ESC_NODE_ID 11
#define LED_PIN 2
#define HEARTBEAT_LED_PIN 13
#define CAN_STB 21
// Match TWR CAN1 routing on Teensy 4.0: RX=pin 23, TX=pin 22.
// FlexCAN_T4 setRX()/setTX() takes a FLEXCAN_PINS enum, not literal GPIO pins.
#define CAN1_PINSEL DEF
// Match TWR CAN2 routing on Teensy 4.0: RX=pin 0, TX=pin 1.
#define CAN2_PINSEL DEF

// --- Ring buffer for safe message passing ---
const int BUF_SIZE = 256;
CAN_message_t rxBuf[BUF_SIZE];
volatile int head = 0, tail = 0;
volatile uint32_t rx_drop_count = 0;

static const uint32_t POSVEL_PRINT_PERIOD_US = 10000;  // 100 Hz total
static const uint32_t SUMMARY_PRINT_PERIOD_US = 1000000;  // 1 Hz
static const uint32_t IQREQ_HEARTBEAT_PERIOD_US = 2000000;  // 0.5 Hz optional zero-torque sync pulse
static const bool IQREQ_HEARTBEAT_ENABLE = false;
static const bool POSVEL_VALUE_PRINT_ENABLE = true;
static const bool POSVEL_TIMER_PRINT_ENABLE = false;
static const bool SUMMARY_PRINT_ENABLE = false;
static const uint32_t HEARTBEAT_TOGGLE_MS = 250;
static volatile uint32_t posvel_active_until_ms = 0;
static uint32_t rx_total_count = 0;
static uint32_t rx_can1_count = 0;
static uint32_t rx_can2_count = 0;
static uint32_t rx_ext_count = 0;
static uint32_t rx_std_count = 0;
static uint32_t posvel_total_count = 0;
static uint32_t posvel_print_count = 0;
static uint32_t posvel_print_skip_count = 0;
static uint32_t last_rx_id = 0;
static uint32_t last_rx_mid = 0;
static uint8_t last_rx_extended = 0;

struct LatestPosVel {
  float pos = 0.0f;
  float vel = 0.0f;
  uint32_t t_us = 0;
  uint32_t dt_us = 0;
  uint32_t count = 0;
  bool valid = false;
};

static LatestPosVel latest_posvel[256];
static uint32_t latest_posvel_printed_count[256] = {0};
static uint32_t latest_posvel_timer_printed_count[256] = {0};
static uint8_t latest_posvel_print_cursor = 0;
static uint8_t latest_posvel_timer_print_cursor = 0;

static uint32_t makeExtId(uint16_t msg_id, uint8_t sender, uint8_t receiver) {
  return ((uint32_t)msg_id << 16) |
         ((uint32_t)receiver << 8) |
         sender;
}

static void packFloat(float val, uint8_t *buf) {
  memcpy(buf, &val, sizeof(float));
}

static const uint32_t LED_ACTIVE_MS = 500;   // blink this long after last RX frame
static const uint32_t LED_TOGGLE_MS = 100;   // 100ms toggle => 5 Hz blink
static volatile uint32_t led_active_until_ms = 0;

static inline void noteCanRxActivity() {
  uint32_t now = millis();
  led_active_until_ms = now + LED_ACTIVE_MS;
}

static inline void notePosVelActivity() {
  uint32_t now = millis();
  posvel_active_until_ms = now + LED_ACTIVE_MS;
}

static inline void serviceRxLed() {
  static uint32_t last_toggle_ms = 0;
  static bool led_state = false;

  uint32_t now = millis();
  bool active = (int32_t)(led_active_until_ms - now) > 0;
  active = (int32_t)(posvel_active_until_ms - now) > 0;

  if (!active) {
    led_state = false;
    digitalWrite(LED_PIN, LOW);
    return;
  }

  if (now - last_toggle_ms >= LED_TOGGLE_MS) {
    last_toggle_ms = now;
    led_state = !led_state;
    digitalWrite(LED_PIN, led_state ? HIGH : LOW);
  }
}

static inline void serviceHeartbeatLed() {
  static uint32_t last_toggle_ms = 0;
  static bool led_state = false;
  const uint32_t now = millis();
  if ((uint32_t)(now - last_toggle_ms) < HEARTBEAT_TOGGLE_MS) return;
  last_toggle_ms = now;
  led_state = !led_state;
  digitalWrite(HEARTBEAT_LED_PIN, led_state ? HIGH : LOW);
}

bool bufferPush(const CAN_message_t &msg) {
  int next = (head + 1) % BUF_SIZE;
  if (next == tail) {
    rx_drop_count++;
    return false;
  }
  rxBuf[head] = msg;
  head = next;
  return true;
}

bool bufferPop(CAN_message_t &msg) {
  if (head == tail) return false; // empty
  msg = rxBuf[tail];
  tail = (tail + 1) % BUF_SIZE;
  return true;
}

// --- POSVEL handler ---
void handlePosVel(const CAN_message_t &msg) {
  uint8_t sender = (msg.id) & 0xFF;
  posvel_total_count++;
  notePosVelActivity();

  if (msg.len == 8) {
    float pos, vel;

    uint32_t u0 = (uint32_t)msg.buf[0] |
                  ((uint32_t)msg.buf[1] << 8) |
                  ((uint32_t)msg.buf[2] << 16) |
                  ((uint32_t)msg.buf[3] << 24);

    uint32_t u1 = (uint32_t)msg.buf[4] |
                  ((uint32_t)msg.buf[5] << 8) |
                  ((uint32_t)msg.buf[6] << 16) |
                  ((uint32_t)msg.buf[7] << 24);

    memcpy(&pos, &u0, sizeof(float));
    memcpy(&vel, &u1, sizeof(float));

    const uint32_t now_us = micros();
    LatestPosVel &latest = latest_posvel[sender];
    latest.pos = pos;
    latest.vel = vel;
    latest.dt_us = latest.valid ? (uint32_t)(now_us - latest.t_us) : 0u;
    latest.t_us = now_us;
    latest.count++;
    latest.valid = true;

    // (kept your placeholder logic)
    if (vel > -20.0f && vel < 20.0f && (vel > 0.1f || vel < -0.1f)) {
    }
  }
}

void printLatestPosVelIfDue() {
  if (!POSVEL_VALUE_PRINT_ENABLE) return;

  static uint32_t last_print_us = 0;
  const uint32_t now_us = micros();
  if ((uint32_t)(now_us - last_print_us) < POSVEL_PRINT_PERIOD_US) return;

  for (uint16_t i = 0; i < 256; ++i) {
    const uint8_t sender = (uint8_t)(latest_posvel_print_cursor + i);
    LatestPosVel &latest = latest_posvel[sender];
    if (!latest.valid || latest.count == latest_posvel_printed_count[sender]) continue;

    char line[96];
    const int len = snprintf(line, sizeof(line),
                             "{\"t_us\":%lu,\"sender\":%u,\"pos\":%.6f,\"vel\":%.6f}\r\n",
                             latest.t_us, sender, latest.pos, latest.vel);
    if (len <= 0 || len >= (int)sizeof(line)) {
      latest_posvel_printed_count[sender] = latest.count;
      posvel_print_skip_count++;
      return;
    }

    Serial.write((const uint8_t*)line, (size_t)len);
    latest_posvel_printed_count[sender] = latest.count;
    latest_posvel_print_cursor = sender + 1u;
    last_print_us = now_us;
    posvel_print_count++;
    return;
  }
}
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

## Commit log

2023-07-14 more schematic work
    [data_logger.kicad_sch]
2023-07-20 more layout
    [data_logger.kicad_sch]
2023-07-24 finishing pcb layout
    [data_logger.kicad_pcb, data_logger.kicad_sch]
2023-07-24 finalized pcb
    [data_logger.kicad_pcb, data_logger.kicad_sch]
2023-07-24 finished design
    [data_logger.kicad_pcb, data_logger.kicad_sch]
2023-07-25 manufacturing files
    [data_logger-B_Cu.gbr, data_logger-B_Mask.gbr, data_logger-B_Paste.gbr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]
2023-07-25 ORDERED FROM JLCPCB
    [data_logger-B_Cu.gbr, data_logger-B_Mask.gbr, data_logger-B_Paste.gbr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]
2023-08-11 fixed mistakes in V1.0, added in all firmware code
    [data_logger-B_Cu.gbr, data_logger-B_Mask.gbr, data_logger-B_Paste.gbr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]
2023-08-22 drew the schematic
2023-09-02 more firmware work
    [data_logger.kicad_sch]
2025-08-03 global name changes for all files
    [ESP32.kicad_sch, POWER.kicad_sch, VESC_brain_board.kicad_pcb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]
2025-08-04 nother checkin
    [ESP32.kicad_sch]
2025-08-05 finished V1.0
    [ESP32.kicad_sch, VESC_brain_board.kicad_pcb, VESC_brain_board.kicad_sch]
2025-08-06 finalized PCB, changed file names
    [ESP32.kicad_sch, MESC_brain_board.kicad_pcb, MESC_brain_board.kicad_sch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]
2025-08-06 finalizing PCB
    [ESP32.kicad_sch, MESC_brain_board.kicad_pcb, MESC_brain_board.kicad_sch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]
2025-08-06 First board ordered from JLCPCB
    [MESC_brain_board.kicad_pcb, MESC_brain_board.kicad_sch, POWER.kicad_sch]
2025-08-19 added MT6701 board
    [MT6701_ENCODER.kicad_pcb, MT6701_ENCODER.kicad_sch]
2025-08-19 used for jlcpcb
    [MT6701_ENCODER.kicad_pcb, outline.dxf]
2025-08-20 started board testing
2025-08-20 update grn LED resistor
    [MESC_brain_board.kicad_pcb, POWER.kicad_sch]
2025-08-22 new code in brain board
2025-08-27 started brain board framework
2026-02-02 CAD work
2026-02-13 minor stuff
    [Untitled.3dm, battery.stl, battery_clamp.stl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]
2026-02-14 balancing work and documentation
    [MT6701_ENCODER-B_Cu.dxf, MT6701_ENCODER-B_Mask.dxf, MT6701_ENCODER-B_Paste.dxf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]
2026-02-16 refined vibration_test
    [MT6701_ENCODER-B_Cu.dxf, MT6701_ENCODER-B_Mask.dxf, MT6701_ENCODER-B_Paste.dxf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]
2026-02-24 created encoder_testing, telemtry chain over ESP32
    [DEV-15583.step, ESP32.kicad_sch, MESC_brain_board-B_Cu.dxf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]
2026-02-24 brain board V1.4
    [CAN.kicad_sch, MESC_brain_board.kicad_pcb, MESC_brain_board.kicad_sch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]
2026-02-25 finalization of BB V1.4
    [CAN.kicad_sch, MESC_brain_board.kicad_pcb, MESC_brain_board.kicad_sch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]
2026-03-02 encoder work
    [MESC_brain_board.kicad_pcb, MESC_brain_board.kicad_sch, POWER.kicad_sch]
2026-03-02 updated brainboard v1.4
    [CAN.kicad_sch, MESC_brain_board.kicad_pcb, MESC_brain_board.kicad_sch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]
2026-03-07 more CAN debugging
    [scrap.3dm]
2026-03-21 worked on position control
    [CAN.kicad_sch, DEV-15583.step, ESP32.kicad_sch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]
2026-03-23 positional control work
    [mechanical.dxf, moteus_adaptor-B_Cu.dxf, moteus_adaptor-B_Mask.dxf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]
2026-03-30 reasonable balance control, has minor drift issues
    [CAN_helper.cpp, CAN_helper.h, ICM42688.cpp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]
2026-04-16 added virtual axle to reduce arc/drift to one side
    [balance_TWR_mode.cpp, main.cpp]
2026-04-17 pretty good balancing in TWR
    [GB36-2_flat.3dm]
2026-04-22 TWR -> ESP32/wifi_repeater -> connect_raw.py working
    [GB36-2_flat.3dm]
2026-04-23 TWR -> ESP32/wifi_repeater improved packet sending
2026-05-04 working on motor damping docs
2026-05-19 completed more modeling of GB36-2
    [Farm-All Tractor rusty obj.3dm]
2026-05-22 Fix ESC POSVEL scheduler wrap and retire IQREQ keepalive workaround
    Add wrap-safe CAN telemetry timebase for autonomous POSVEL scheduling.
    Preserve IQREQ-triggered POSVEL sync/nudge behavior, restore POSVEL payload to position radians + velocity rad/s, keep ESC diagnostic status frames available for CAN bench testing, and update can_posvel_read docs to disable the zero-IQREQ keepalive by default.
    [ICM42688.cpp, main.cpp]
2026-05-31 motor docs
